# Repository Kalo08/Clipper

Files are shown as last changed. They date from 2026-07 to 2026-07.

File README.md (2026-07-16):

CLIPPER

This project uses a simple robotic arm driven by servos and controlled by a vr headset and controllers. it connects to the headset to feed real time data back to the servos to manipulate the arm. the arm has hair clippers attached, and can be used to cut hair. The headset communicates to a rasberry pi using UDP and sends servo commands. The pi drives the servos through its gpio ports and the servos have power through a simple battery pack and bread board.

https://www.youtube.com/watch?v=h8sehnFcGIc&authuser=0

Heres a YouTube Video explaining how everything works!

clipper



Here are pictures of the finalized arm! It has the a base that allows it to rotate, move up and down, and stay attached ot teh table. That connects to the elbow which allows us to move the clippers even more. 

Wiring: The Pi is powered and connects to the servos. The Pi communicates to our computer. The computer facilitates it comunication with the VR head set. When the VR headset communicates to the Pi, and this tells the pi to activates the servos. The code tells the servos which ones need to go to keep in sync with the VR.

| Item | Qty | Unit Price (USD) | Line Total (USD) | Notes |
| :--- | :--- | :--- | :--- | :--- |
| Raspberry Pi 4 (4GB) | 1 | 55.00 | 55.00 | MSRP; 2GB ~$45 / 8GB ~$75 |
| SG90 Micro Servo | 3 | 4.00 | 12.00 | ~$3-5 each; often cheaper in multipacks |
| Hair Trimmer | 1 | 25.00 | 25.00 | Price provided |
| Aluminum Extrusion (2020 T-slot 1m) | 1 | 12.00 | 12.00 | Varies by profile and length |
| Battery Pack (USB power bank) | 1 | 15.00 | 15.00 | ~10000mAh; Pi 4 needs 5V/3A output |
| Breadboard (830-point) | 1 | 5.00 | 5.00 | Half-size ~$3 |
| Jumper Wires (120pc M-M/M-F/F-F kit) | 1 | 6.00 | 6.00 | Mixed kit |
| Total |  |  | 130.00 |  |

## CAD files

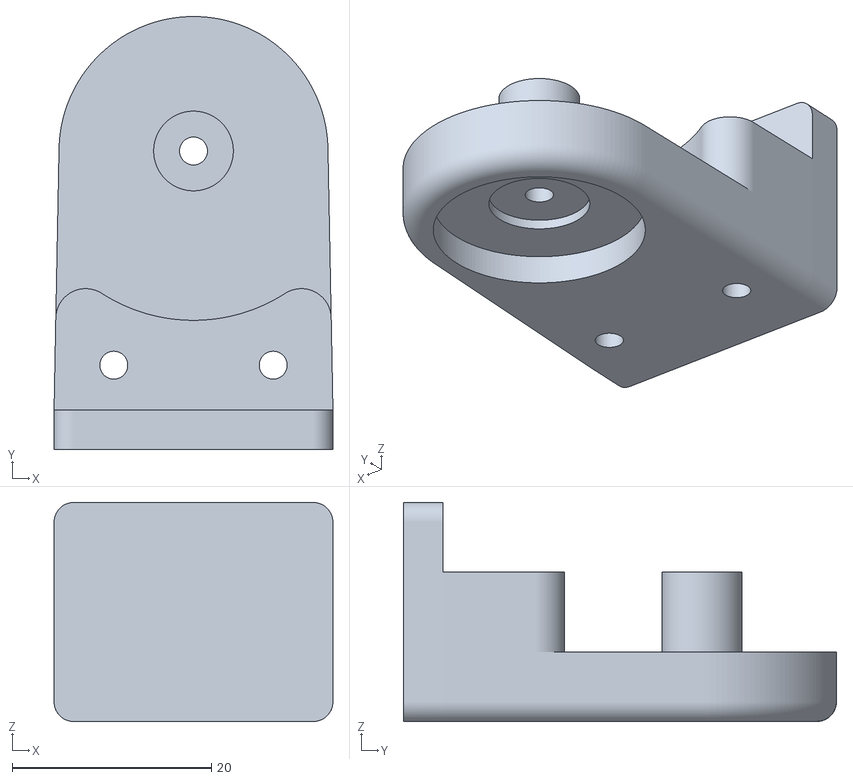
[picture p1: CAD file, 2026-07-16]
CAD /Elbow joint top.stl
28.0 x 43.5 x 22.0

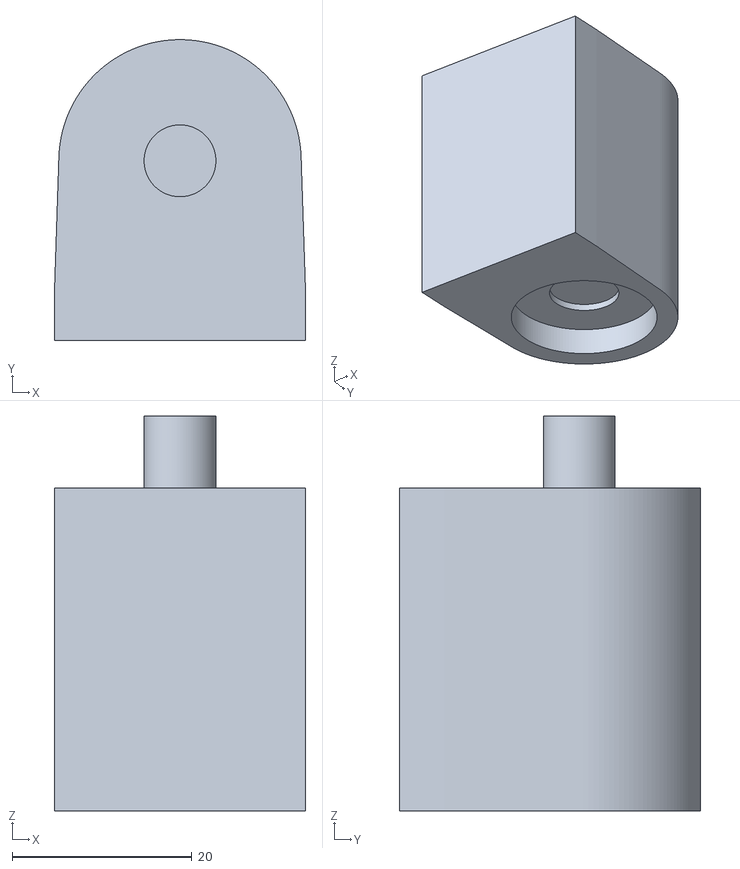
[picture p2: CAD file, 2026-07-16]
CAD /Base joint.stl
28.0 x 33.5 x 44.0

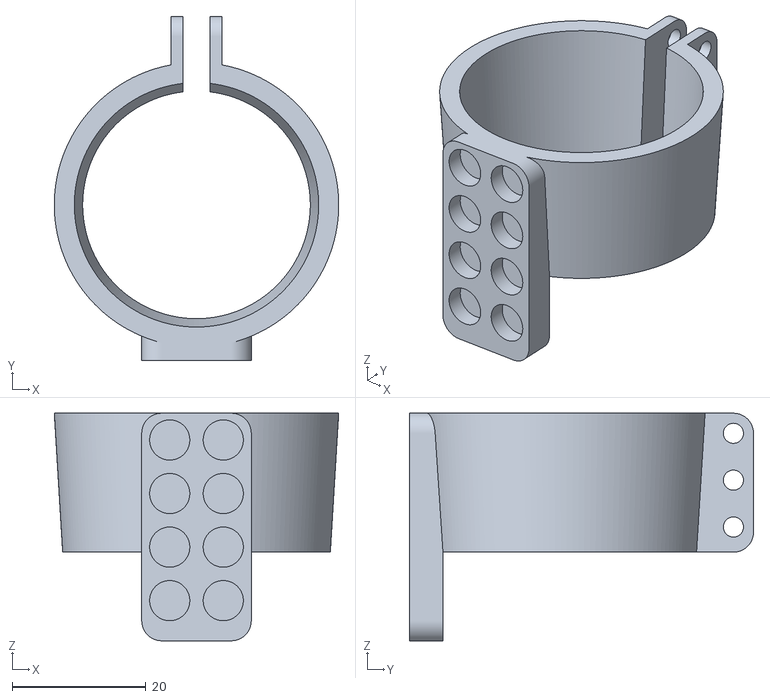
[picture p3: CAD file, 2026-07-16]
CAD /Trimmer holder.stl
42.5 x 51.4 x 34.0

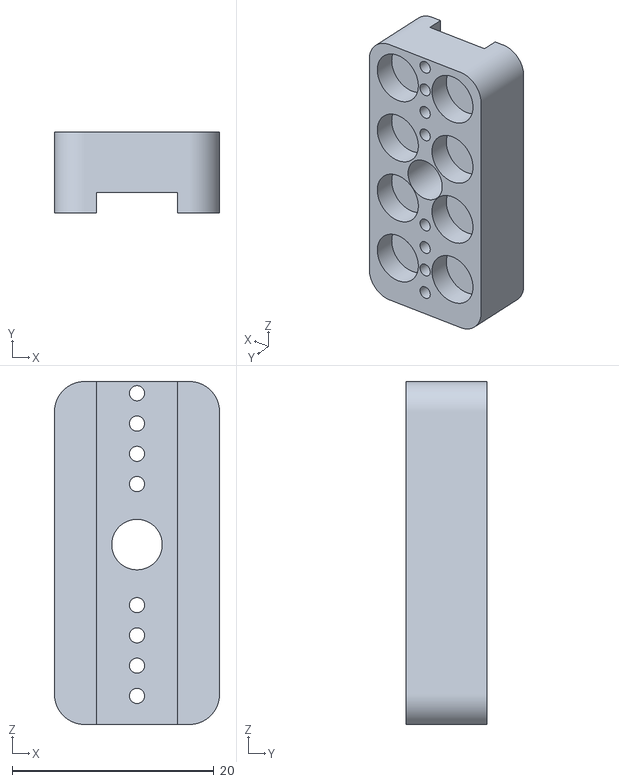
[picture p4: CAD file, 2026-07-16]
CAD /Trimmer holder servo attachment.stl
16.4 x 8.00 x 34.0

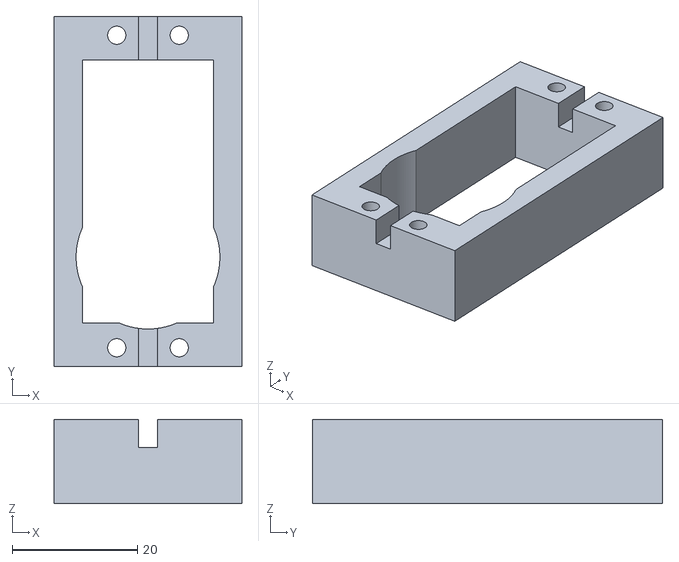
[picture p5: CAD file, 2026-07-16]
CAD /Base servo holder.stl
30.0 x 56.0 x 13.5

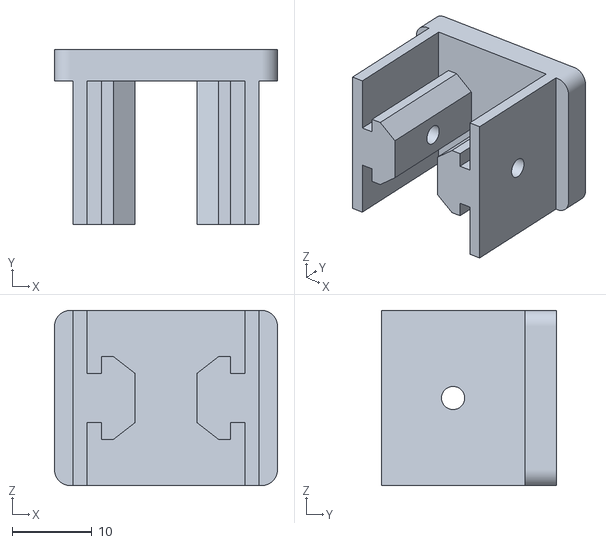
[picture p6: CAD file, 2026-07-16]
CAD /arm attachment.stl
28.0 x 22.0 x 22.0

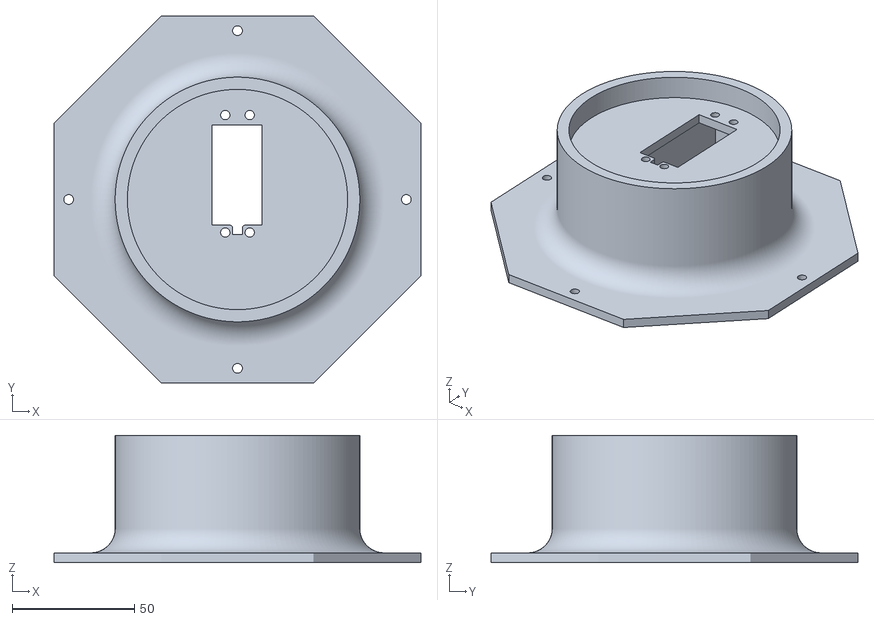
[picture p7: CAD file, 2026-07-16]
CAD /Base bottom.stl
150.0 x 150.0 x 52.0

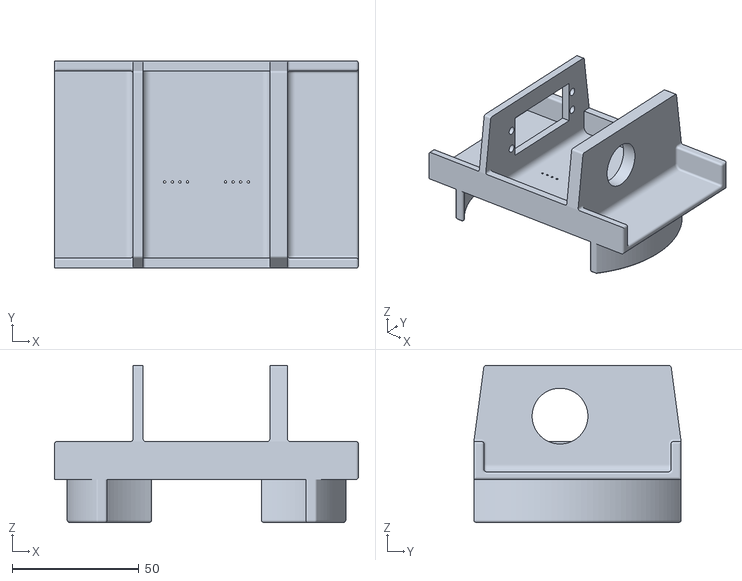
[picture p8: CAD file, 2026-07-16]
CAD /Base top.stl
120.0 x 81.8 x 62.0

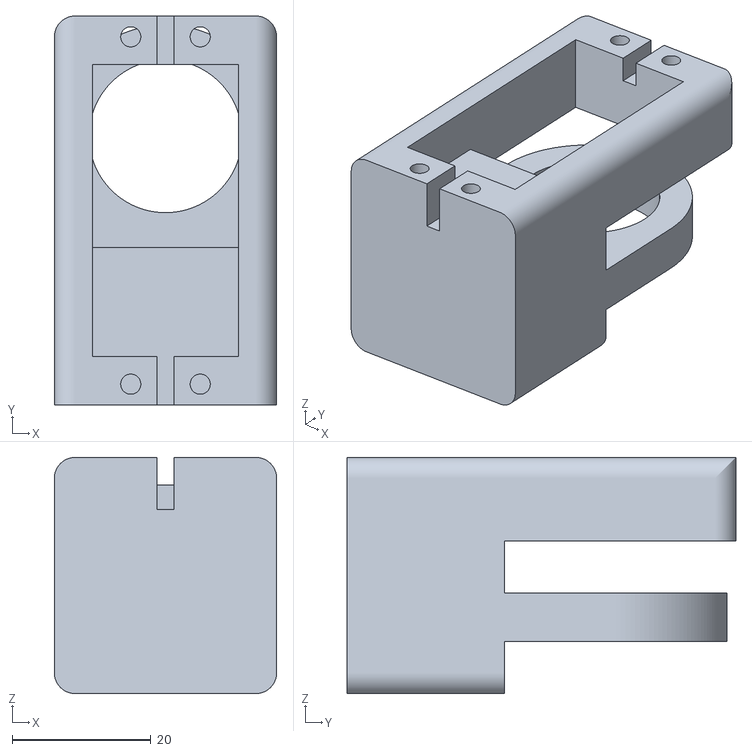
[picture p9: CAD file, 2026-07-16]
CAD /Elbow bottom.stl
32.0 x 56.0 x 34.0

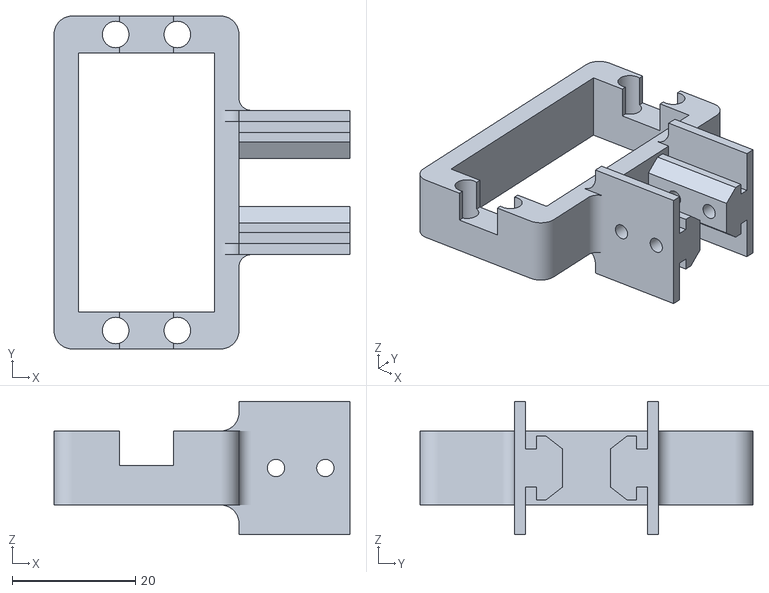
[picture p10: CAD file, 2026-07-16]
CAD /Wrist servo holder.stl
48.0 x 54.0 x 21.6

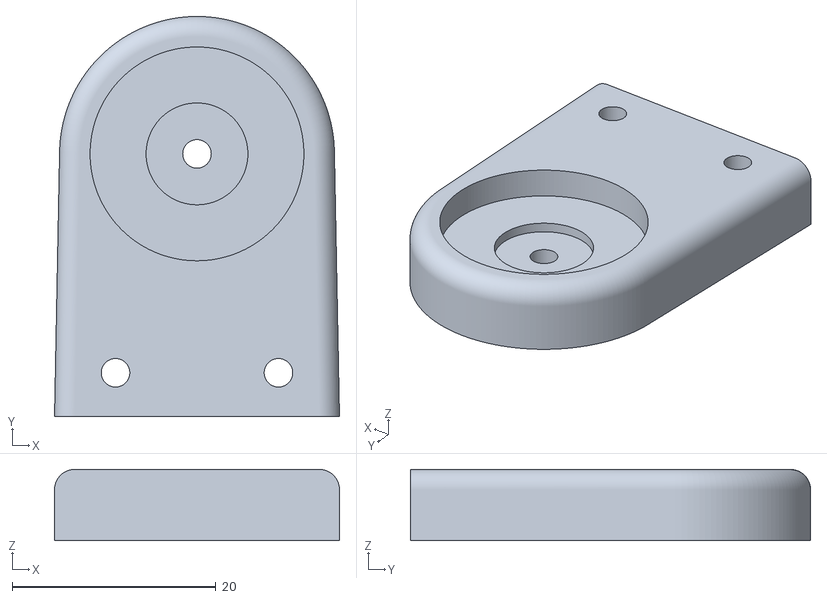
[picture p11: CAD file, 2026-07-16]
CAD /Elbow joint insert.stl
28.0 x 39.3 x 7.00

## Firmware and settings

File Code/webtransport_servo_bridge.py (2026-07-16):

"""
WebTransport (QUIC) → Servo Bridge
Receives compact binary datagrams from the Meta Quest WebXR page
and drives servos directly via Pi GPIO PWM (no PCA9685 driver board).

Packet format (matches webxr_controller.html):
    1 byte  → command byte (0x01 = spin stepper 1 one revolution)
    3 bytes → servo angles [S1, S2, S3], each 0-180
        byte 0 → S1 angle  (0–180)  base rotation (pan / yaw)        → GPIO27 (physical pin 13)
        byte 1 → S2 angle  (0–180)  joint on base (tilt / pitch)     → GPIO17 (physical pin 11)
        byte 2 → S3 angle  (0–180)  roll                             → GPIO22 (physical pin 15)
        byte 3 → S4 angle  (0–180)  driven by analog trigger, 90=up/0=down → GPIO4 (physical pin 7)
        byte 4 → trigger strength (0-255), informational only

Wiring (servo → Pi 4):
    Signal → GPIO27 / GPIO17 / GPIO22 / GPIO4 (physical pins 13 / 11 / 15 / 7)
    S2B (second shoulder servo, mirrored follower of S2) → GPIO18 (physical pin 12)
    V+     → 5–6 V external supply for servos (NOT the Pi's 5V pin)
    GND    → common ground with the Pi

Dependencies (install on the Pi):
    pip install aioquic gpiozero lgpio RPi.GPIO

gpiozero + lgpio drive the servo PWM directly (no daemon needed) via the
modern GPIO chardev interface — works on current Raspberry Pi OS releases
where the unmaintained `pigpio` package is no longer available.

Generate your TLS cert first:
    python setup_cert.py

Run:
    python webtransport_servo_bridge.py

Then open webxr_controller.html on the Meta Quest Browser,
paste the cert hash printed by setup_cert.py, and hit Connect.
"""

import asyncio
import logging
import signal
import sys
import threading
import time
from datetime import datetime
from pathlib import Path

# ── gpiozero / lgpio (direct GPIO PWM for servos) ─────────────────────────────
SIMULATE = False
_AngularServo = None
try:
    from gpiozero import AngularServo, Device
    from gpiozero.pins.lgpio import LGPIOFactory
    Device.pin_factory = LGPIOFactory()
    _AngularServo = AngularServo
except Exception as e:
    SIMULATE = True
    print(f"[bridge] gpiozero/lgpio unavailable ({e}) — SIMULATE mode (no servo output).")

# ── Stepper GPIO import ───────────────────────────────────────────────────────
try:
    import RPi.GPIO as GPIO
    GPIO.setmode(GPIO.BCM)
    GPIO.setwarnings(False)
    _GPIO_OK = True
except (ImportError, RuntimeError):
    _GPIO_OK = False

# ── aioquic imports ───────────────────────────────────────────────────────────
try:
    from aioquic.asyncio import serve
    from aioquic.asyncio.protocol import QuicConnectionProtocol
    from aioquic.h3.connection import H3_ALPN, H3Connection
    from aioquic.h3.events import (
        DatagramReceived,
        H3Event,
        HeadersReceived,
        WebTransportStreamDataReceived,
    )
    from aioquic.quic.configuration import QuicConfiguration
    from aioquic.quic.events import ProtocolNegotiated, QuicEvent
except ImportError:
    print("ERROR: 'aioquic' not installed.  Run:  pip install aioquic")
    sys.exit(1)

# ── Config ────────────────────────────────────────────────────────────────────
HOST      = "0.0.0.0"
PORT      = 4433
CERT_FILE = Path("cert.pem")
KEY_FILE  = Path("key.pem")
WT_PATH   = "/servo"        # Must match the URL in webxr_controller.html

# GPIO pin (BCM numbering) for each servo's PWM signal wire
SERVO_GPIO = {"s1": 27, "s2": 17, "s3": 22, "s4": 4, "s2b": 18}

# s2b is a second shoulder servo mounted on the OPPOSITE side of the joint
# from s2, driving the first linkage in unison with it. Because it faces the
# other way it always follows s2 at the mirrored angle (180 - s2) — driving
# both to the same angle would make them fight each other and stall.
SERVO_FOLLOWERS = {"s2": ("s2b", lambda a: 180 - a)}

# The follower tracks the master's position from this long ago, tracing the
# same motion path uniformly time-shifted. Only useful for a TRUE timing
# mismatch — a lead/lag that flips with direction (in sync one way, delayed
# the other) is an angle offset and needs TRIM below, not delay.
SERVO_FOLLOWER_DELAY_S = 0.0

# Constant trim added to s2b's mirrored angle, correcting a horn seated a few
# degrees off true mirror. Tune this ONLY once behavior is consistent
# (stable power, no random twitching) — calibrating against noise is
# meaningless. Symptom of needing trim: lead/lag that flips with sweep
# direction, the same way every sweep.
SERVO_FOLLOWER_TRIM_DEG = 0.0

# Startup pose per servo (defaults to 0).
# s1 starts centred (90 = "facing forward" once calibrated) rather than at
# its 0 default — with the s1 mirror below, initial_angle=0 would otherwise
# swing the base to its opposite physical extreme for no reason at cold start.
# s2 starts at 90 = arm straight up; s2b mirrors that as 180 - 90 = 90.
SERVO_INIT = {"s1": 90, "s2": 90, "s2b": 90}

# Pulse width range for 0-180 degrees (microseconds) — standard hobby servo range
SERVO_MIN_US = 500
SERVO_MAX_US = 2500

# Hard safety limits — servos are never driven outside these ranges, regardless
# of what a client requests. Physical range is still 0-180 (see AngularServo
# below); this just clamps the usable travel.
#   s1 (base)          — full range, no clamp
#   s2/s3/s4 (joints)  — clamped to ±85° around centre (90°), a few degrees
#                        short of the mechanical stops
SERVO_LIMITS = {
    "s1":  (0, 180),
    "s2":  (5, 90),     # 90 = straight up; angle DECREASES as the arm tips forward
    "s2b": (90, 175),   # mirrored image of s2's range (180 - [5, 90])
    "s3":  (5, 175),
    "s4":  (5, 175),
}

# NOTE: an s2 direction-reversal mirror (angle -> 180 - angle) was tried here
# and reverted — logical angle 0 is confirmed to be the arm's straight-up
# rest pose, and mirroring the whole 0-180 range moves that reference to the
# opposite physical extreme (0 -> 180), which is NOT "up". A full-range
# reversal is only safe when the joint's reference position sits at the
# CENTRE (90) rather than an endpoint — see s1 below, where that holds.
#
# s1 (base) swings the wrong horizontal direction — target-right commands
# spin it left. s1's reference ("facing forward" at calibration) is at the
# CENTRE of its range (90°), not an endpoint, so mirroring is safe here:
# 180 - 90 = 90, the centre — and therefore the calibration reference —
# stays fixed while the direction of swing flips.
SERVO_INVERT = {"s1"}


def _phys_angle(key: str, angle: float) -> float:
    return 180 - angle if key in SERVO_INVERT else angle

# A4988 stepper driver — stepper 1 (BCM numbering)
STEP1_PIN       = 23   # physical pin 16 — A4988 STEP
DIR1_PIN        = 24   # physical pin 18 — A4988 DIR
STEPPER1_STEPS  = 200  # steps per full revolution (1.8°/step motor, full-step mode)
STEPPER1_DELAY  = 0.002  # seconds per half-pulse — lower = faster spin

# ── Logging ───────────────────────────────────────────────────────────────────
logging.basicConfig(
    level=logging.INFO,
    format="%(asctime)s  %(levelname)-7s  %(message)s",
    datefmt="%H:%M:%S",
)
log = logging.getLogger("wt-bridge")
logging.getLogger("aioquic").setLevel(logging.WARNING)   # silence QUIC noise

# ── Servo state ───────────────────────────────────────────────────────────────
# Bookkeeping must start at the SAME logical angle each servo is actually
# initialised to (SERVO_INIT), or the slew loop's first move jump-cuts from
# a stale "0" instead of continuing smoothly from where the servo really is.
current_angles = {key: SERVO_INIT.get(key, 0) for key in SERVO_GPIO}
target_angles  = dict(current_angles)
_slew_stop = None   # threading.Event, created when the slew loop starts

# Stats
pkt_count  = 0
last_stats = time.monotonic()


servos = {}   # key -> AngularServo instance, populated by init_servos()


def init_servos():
    if SIMULATE:
        log.info("SIMULATE mode — gpiozero not initialised.")
        return
    for key, gpio in SERVO_GPIO.items():
        init_angle = SERVO_INIT.get(key, 0)
        servos[key] = _AngularServo(
            gpio,
            initial_angle=_phys_angle(key, init_angle),
            min_angle=0,
            max_angle=180,
            min_pulse_width=SERVO_MIN_US / 1_000_000,
            max_pulse_width=SERVO_MAX_US / 1_000_000,
        )
        log.info(f"  GPIO{gpio} → {key.upper()} initialised ({init_angle}°)")


def move_servo(key: str, angle: int):
    # Master/slave: commands only set TARGETS. The pose loop below owns all
    # hardware writes, pushing the latest commanded pose out each tick —
    # master and follower (s2b) in the same tick, no rate limiting.
    lo, hi = SERVO_LIMITS[key]
    angle = max(lo, min(hi, angle))
    target_angles[key] = angle


def _pose_loop():
    from collections import deque
    # 50 Hz — matches the servo pulse rate. Updating pulse widths faster
    # than the servos consume them (e.g. 100 Hz) risks mid-pulse glitches
    # with software-timed PWM, which shows up as random twitching.
    TICK = 0.02
    # -1: the loop ordering (target read → write → history append) already
    # contributes one tick of inherent lag
    delay_ticks = max(0, round(SERVO_FOLLOWER_DELAY_S / TICK) - 1)
    # Per-master ring buffer of past positions; the oldest entry is the
    # master's angle SERVO_FOLLOWER_DELAY_S ago once the buffer fills.
    history = {m: deque([current_angles[m]] * (delay_ticks + 1),
                        maxlen=delay_ticks + 1)
               for m in SERVO_FOLLOWERS}

    while not _slew_stop.is_set():
        # Followers chase the master's (possibly delayed) position
        for master, (fkey, transform) in SERVO_FOLLOWERS.items():
            flo, fhi = SERVO_LIMITS[fkey]
            target_angles[fkey] = max(flo, min(fhi,
                transform(history[master][0]) + SERVO_FOLLOWER_TRIM_DEG))

        # Write the latest pose straight through — no stepping. The servos
        # hold whatever pose was last written (PWM stays active) until the
        # next change arrives.
        for key in SERVO_GPIO:
            tgt = target_angles[key]
            if current_angles[key] != tgt:
                current_angles[key] = tgt
                if not SIMULATE:
                    servos[key].angle = _phys_angle(key, tgt)

        for master in history:
            history[master].append(current_angles[master])
        time.sleep(TICK)


def start_pose_loop():
    global _slew_stop
    _slew_stop = threading.Event()
    threading.Thread(target=_pose_loop, daemon=True, name="servo-pose").start()
    log.info("Servo pose loop started (50 Hz, direct pose writes).")


def cleanup_servos():
    if not SIMULATE:
        # Stop the pose loop, then release the pins WITHOUT moving anything —
        # servos hold their last commanded position while powered and simply
        # stop receiving pulses where they are.
        if _slew_stop is not None:
            _slew_stop.set()
            time.sleep(0.05)
        for key, servo in servos.items():
            try:
                servo.close()
            except Exception:
                pass
    if _GPIO_OK:
        GPIO.cleanup()


def bar(a: int, w: int = 16) -> str:
    n = int((a / 180) * w)
    return f"[{'#'*n}{'-'*(w-n)}]{a:>4}°"


# ── Per-channel servo "spin" test ────────────────────────────────────────────
SERVO_SPIN_CMDS = {0x02: "s1", 0x03: "s2", 0x04: "s3"}

# Guards against overlapping motions: pressing a spin button twice (or angle
# packets streaming in mid-sweep) would otherwise interleave two writers on
# the same servo, which shows up as erratic continuous sweeping.
_busy_lock = threading.Lock()
_busy: set[str] = set()


def _claim(key: str) -> bool:
    with _busy_lock:
        if key in _busy:
            return False
        _busy.add(key)
        return True


def _release(key: str):
    with _busy_lock:
        _busy.discard(key)


def sweep_servo(key: str, delay: float = 0.01):
    """Blocking sweep lo -> hi -> lo across this servo's SERVO_LIMITS — run off the event loop (see run_in_executor call site)."""
    if SIMULATE:
        log.info(f"SIMULATE: would sweep servo {key}.")
        return
    if not _claim(key):
        log.info(f"Servo {key.upper()} sweep already running — ignored.")
        return
    lo, hi = SERVO_LIMITS[key]
    try:
        for angle in list(range(lo, hi + 1, 2)) + list(range(hi, lo - 1, -2)):
            move_servo(key, angle)
            time.sleep(delay)
        log.info(f"Servo {key.upper()} sweep complete.")
    finally:
        _release(key)


# ── Stepper 1 (A4988) ─────────────────────────────────────────────────────────

def init_stepper1():
    if not _GPIO_OK:
        return
    GPIO.setup(STEP1_PIN, GPIO.OUT)
    GPIO.setup(DIR1_PIN, GPIO.OUT)
    GPIO.output(STEP1_PIN, GPIO.LOW)
    GPIO.output(DIR1_PIN, GPIO.HIGH)
    log.info(f"  GPIO {STEP1_PIN} → STEP1, GPIO {DIR1_PIN} → DIR1 initialised")


def spin_stepper1(steps: int = STEPPER1_STEPS, delay: float = STEPPER1_DELAY):
    """Blocking step loop — run this off the asyncio event loop (see run_in_executor call site)."""
    if not _GPIO_OK:
        log.info(f"SIMULATE: would spin stepper 1 for {steps} steps.")
        return
    if not _claim("stepper1"):
        log.info("Stepper 1 already spinning — ignored.")
        return
    try:
        for _ in range(steps):
            GPIO.output(STEP1_PIN, GPIO.HIGH)
            time.sleep(delay)
            GPIO.output(STEP1_PIN, GPIO.LOW)
            time.sleep(delay)
        log.info(f"Stepper 1 spun {steps} steps.")
    finally:
        _release("stepper1")


_last_seq = None


def handle_packet(data: bytes):
    """
    Decode an incoming datagram.
      1 byte  -> command byte (0x01 = spin stepper 1 one revolution)
      6 bytes -> servo angle packet [seq, s1, s2, s3, s4, strength]

    seq is a wrapping 0-255 counter. QUIC datagrams arrive unordered, so a
    stale mid-motion packet can land AFTER the newest one — without this
    check it would overwrite the final position with an earlier angle.
    Packets more than half the wrap window behind the newest seen are
    discarded as stale.
    """
    global pkt_count, _last_seq

    if len(data) == 1:
        cmd = data[0]
        if cmd == 0x01:
            log.info("Command received: spin stepper 1")
            asyncio.get_event_loop().run_in_executor(None, spin_stepper1)
        elif cmd in SERVO_SPIN_CMDS:
            key = SERVO_SPIN_CMDS[cmd]
            log.info(f"Command received: spin servo {key.upper()}")
            asyncio.get_event_loop().run_in_executor(None, sweep_servo, key)
        return

    if len(data) < 6:
        return

    seq = data[0]
    if _last_seq is not None:
        ahead = (seq - _last_seq) & 0xFF
        if ahead == 0 or ahead > 128:   # duplicate or stale (arrived late)
            return
    _last_seq = seq

    s1, s2, s3, s4 = data[1], data[2], data[3], data[4]

    # Validate range — ignore garbage
    if not (0 <= s1 <= 180 and 0 <= s2 <= 180 and 0 <= s3 <= 180 and 0 <= s4 <= 180):
        return

    # Skip servos mid-sweep so streamed angles don't fight the sweep loop
    for key, val in (("s1", s1), ("s2", s2), ("s3", s3), ("s4", s4)):
        if key not in _busy:
            move_servo(key, val)
    pkt_count += 1

    # Print live status every 30 packets instead of every packet
    # to avoid flooding the terminal while keeping feedback visible
    if pkt_count % 30 == 0:
        ts = datetime.now().strftime("%H:%M:%S")
        print(
            f"\r{ts}  S1{bar(s1)}  S2{bar(s2)}  S3{bar(s3)}  S4{bar(s4)}  "
            f"[{pkt_count} pkts]   ",
            end="", flush=True,
        )


# ── WebTransport protocol ─────────────────────────────────────────────────────

class ServoHandler(QuicConnectionProtocol):
    """
    Minimal WebTransport server handler.
    Accepts any WebTransport session on WT_PATH and processes incoming datagrams.
    """

    def __init__(self, *args, **kwargs):
        super().__init__(*args, **kwargs)
        self._h3: H3Connection | None = None
        self._wt_sessions: set[int] = set()   # active WebTransport session IDs

    def quic_event_received(self, event: QuicEvent):
        if isinstance(event, ProtocolNegotiated):
            self._h3 = H3Connection(self._quic, enable_webtransport=True)

        if self._h3:
            for h3_event in self._h3.handle_event(event):
                self._h3_event(h3_event)

    def _h3_event(self, event: H3Event):
        if isinstance(event, HeadersReceived):
            # Inspect CONNECT request headers for WebTransport handshake
            headers = {k: v for k, v in event.headers}
            method  = headers.get(b":method", b"").decode()
            path    = headers.get(b":path",   b"").decode()

            if method == "CONNECT" and path == WT_PATH:
                # Accept the WebTransport session
                self._h3.send_headers(
                    stream_id=event.stream_id,
                    headers=[(b":status", b"200")],
                )
                self._wt_sessions.add(event.stream_id)
                addr = self._quic._network_paths[0].addr if self._quic._network_paths else "?"
                log.info(f"WebTransport session opened from {addr}  (stream {event.stream_id})")
            else:
                # Reject unknown paths
                self._h3.send_headers(
                    stream_id=event.stream_id,
                    headers=[(b":status", b"404")],
                )

        elif isinstance(event, DatagramReceived):
            # QUIC datagrams arrive here — these are our servo packets
            handle_packet(event.data)

        elif isinstance(event, WebTransportStreamDataReceived):
            # Also accept data on WebTransport streams (fallback from browser)
            handle_packet(event.data)


# ── Main ──────────────────────────────────────────────────────────────────────

async def main():
    if not CERT_FILE.exists() or not KEY_FILE.exists():
        print(f"\nERROR: {CERT_FILE} or {KEY_FILE} not found.")
        print("  Run:  python setup_cert.py\n")
        sys.exit(1)

    config = QuicConfiguration(
        alpn_protocols=H3_ALPN,
        is_client=False,
        max_datagram_frame_size=65536,   # enable QUIC datagrams
    )
    config.load_cert_chain(str(CERT_FILE), str(KEY_FILE))

    init_servos()
    init_stepper1()
    start_pose_loop()

    print(f"\n{'=' * 62}")
    print(f"  WebTransport Servo Bridge  (QUIC / UDP-like datagrams)")
    print(f"  Listening on  https://{HOST}:{PORT}{WT_PATH}")
    print(f"  Simulate mode: {SIMULATE}")
    print(f"\n  Servo GPIO map (BCM numbering):")
    for k, gpio in SERVO_GPIO.items():
        print(f"    {k.upper()} → GPIO{gpio}")
    print(f"\n  Stepper 1 (A4988) GPIO map:")
    print(f"    STEP1 → GPIO {STEP1_PIN} (BCM)")
    print(f"    DIR1  → GPIO {DIR1_PIN} (BCM)")
    print(f"\n  Steps:")
    print(f"    1. Find Pi IP:   hostname -I")
    print(f"    2. Open webxr_controller.html on the Quest Browser")
    print(f"    3. Set Pi IP + cert hash (from setup_cert.py) → Connect")
    print(f"\n  Ctrl+C to stop.")
    print(f"{'=' * 62}\n")

    stop = asyncio.get_event_loop().create_future()

    def _sig(*_):
        if not stop.done():
            stop.set_result(None)

    loop = asyncio.get_event_loop()
    for sig in (signal.SIGINT, signal.SIGTERM):
        try:
            loop.add_signal_handler(sig, _sig)
        except NotImplementedError:
            pass

    server = await serve(
        host=HOST,
        port=PORT,
        configuration=config,
        create_protocol=ServoHandler,
    )
    try:
        await stop
    except (asyncio.CancelledError, KeyboardInterrupt):
        pass
    finally:
        server.close()

    print()
    log.info(f"Shutting down.  Total packets received: {pkt_count}")
    cleanup_servos()


if __name__ == "__main__":
    try:
        asyncio.run(main())
    except KeyboardInterrupt:
        pass

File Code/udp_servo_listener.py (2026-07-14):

"""
UDP Servo Data Listener - Test Script
Receives raw UDP packets from Android APK and decodes servo control data
intended for a Raspberry Pi 3.

Expected packet format (sent from Android APK):
  - Simple CSV:   "S1:90,S2:45,S3:120"
  - JSON:         {"s1": 90, "s2": 45, "s3": 120}
  - Binary:       [servo_id (1 byte), angle (1 byte), ...]
  - Raw bytes:    b'\x01\x5a\x02\x2d'  (servo_id, angle pairs)

Run this on your PC or Raspberry Pi 3 to verify the APK is sending
correctly before wiring up actual servo GPIO control.
"""

import socket
import struct
import json
import time
import argparse
from datetime import datetime

# ──────────────────────────────────────────────
# Configuration
# ──────────────────────────────────────────────
DEFAULT_HOST = "0.0.0.0"   # Listen on all interfaces
DEFAULT_PORT = 5005         # Match this in your Android APK
BUFFER_SIZE  = 1024         # Max bytes per UDP packet


# ──────────────────────────────────────────────
# Packet parsers
# ──────────────────────────────────────────────

def try_parse_json(data: bytes) -> dict | None:
    """Try to decode the payload as JSON."""
    try:
        obj = json.loads(data.decode("utf-8"))
        if isinstance(obj, dict):
            return obj
    except (json.JSONDecodeError, UnicodeDecodeError):
        pass
    return None


def try_parse_csv(data: bytes) -> dict | None:
    """
    Try to decode the payload as CSV servo pairs.
    Accepted formats:
        "S1:90,S2:45"
        "1:90,2:45"
        "90,45,120"   (positional, no servo-id prefix)
    """
    try:
        text = data.decode("utf-8").strip()
        servos = {}

        if ":" in text:
            for part in text.split(","):
                part = part.strip()
                if ":" in part:
                    label, val = part.split(":", 1)
                    label = label.strip().upper().lstrip("S")
                    servos[f"S{label}"] = int(val.strip())
        else:
            for i, val in enumerate(text.split(","), start=1):
                servos[f"S{i}"] = int(val.strip())

        return servos if servos else None
    except (ValueError, UnicodeDecodeError):
        pass
    return None


def try_parse_binary(data: bytes) -> dict | None:
    """
    Try to decode the payload as raw binary servo pairs.
    Format: alternating bytes  [servo_id, angle, servo_id, angle, ...]
    Angle clamped to 0-180.
    """
    if len(data) < 2 or len(data) % 2 != 0:
        return None
    servos = {}
    for i in range(0, len(data), 2):
        servo_id = data[i]
        angle    = data[i + 1]
        if not (0 <= angle <= 180):
            return None   # Doesn't look like servo angles
        servos[f"S{servo_id}"] = angle
    return servos if servos else None


def parse_packet(data: bytes) -> tuple[str, dict | None]:
    """
    Attempt all parsers in order of likelihood.
    Returns (format_name, servo_dict) or (format_name, None) if unknown.
    """
    result = try_parse_json(data)
    if result:
        return "JSON", result

    result = try_parse_csv(data)
    if result:
        return "CSV", result

    result = try_parse_binary(data)
    if result:
        return "BINARY", result

    return "UNKNOWN", None


# ──────────────────────────────────────────────
# Display helpers
# ──────────────────────────────────────────────

def servo_bar(angle: int, width: int = 20) -> str:
    """Render a simple ASCII bar for a servo angle (0-180)."""
    filled = int((angle / 180) * width)
    bar = "#" * filled + "-" * (width - filled)
    return f"[{bar}] {angle:>3}°"


def print_servos(fmt: str, servos: dict, addr: tuple, raw: bytes):
    ts = datetime.now().strftime("%H:%M:%S.%f")[:-3]
    print(f"\n{'─' * 52}")
    print(f"  {ts}  from {addr[0]}:{addr[1]}   [{fmt}]")
    print(f"  raw ({len(raw)} bytes): {raw.hex(' ').upper()}")
    print()
    for name, angle in sorted(servos.items()):
        print(f"  {name:>4}  {servo_bar(angle)}")
    print(f"{'─' * 52}")


def print_unknown(addr: tuple, raw: bytes):
    ts = datetime.now().strftime("%H:%M:%S.%f")[:-3]
    print(f"\n[{ts}] UNRECOGNISED packet from {addr[0]}:{addr[1]}")
    print(f"  raw ({len(raw)} bytes): {raw.hex(' ').upper()}")
    try:
        print(f"  utf-8: {raw.decode('utf-8')!r}")
    except UnicodeDecodeError:
        pass


# ──────────────────────────────────────────────
# Main listener
# ──────────────────────────────────────────────

def listen(host: str, port: int, packet_limit: int | None):
    sock = socket.socket(socket.AF_INET, socket.SOCK_DGRAM)
    sock.setsockopt(socket.SOL_SOCKET, socket.SO_REUSEADDR, 1)
    sock.bind((host, port))
    sock.settimeout(1.0)   # Allow Ctrl-C to work cleanly

    print(f"\n{'=' * 52}")
    print(f"  UDP Servo Listener")
    print(f"  Listening on {host}:{port}")
    print(f"  Waiting for packets from Android APK ...")
    if packet_limit:
        print(f"  Will stop after {packet_limit} packets.")
    print(f"  Press Ctrl+C to quit.")
    print(f"{'=' * 52}\n")

    packet_count = 0
    stats = {"json": 0, "csv": 0, "binary": 0, "unknown": 0}

    try:
        while True:
            try:
                data, addr = sock.recvfrom(BUFFER_SIZE)
            except socket.timeout:
                continue

            packet_count += 1
            fmt, servos = parse_packet(data)

            if servos:
                stats[fmt.lower()] = stats.get(fmt.lower(), 0) + 1
                print_servos(fmt, servos, addr, data)
            else:
                stats["unknown"] += 1
                print_unknown(addr, data)

            if packet_limit and packet_count >= packet_limit:
                print(f"\nReached packet limit ({packet_limit}). Stopping.")
                break

    except KeyboardInterrupt:
        pass
    finally:
        sock.close()
        print(f"\n{'=' * 52}")
        print(f"  Session ended. {packet_count} packet(s) received.")
        print(f"  JSON={stats['json']}  CSV={stats['csv']}  "
              f"BINARY={stats['binary']}  UNKNOWN={stats['unknown']}")
        print(f"{'=' * 52}\n")


# ──────────────────────────────────────────────
# CLI entry point
# ──────────────────────────────────────────────

if __name__ == "__main__":
    parser = argparse.ArgumentParser(
        description="Test listener for UDP servo data from an Android APK."
    )
    parser.add_argument(
        "--host", default=DEFAULT_HOST,
        help=f"Interface to bind (default: {DEFAULT_HOST})"
    )
    parser.add_argument(
        "--port", type=int, default=DEFAULT_PORT,
        help=f"UDP port to listen on (default: {DEFAULT_PORT})"
    )
    parser.add_argument(
        "--limit", type=int, default=None,
        help="Stop after N packets (default: run forever)"
    )
    args = parser.parse_args()
    listen(args.host, args.port, args.limit)

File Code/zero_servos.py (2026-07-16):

"""
Zero servos — drives every servo to the arm's zeroed pose and HOLDS it there
(PWM stays active) until you press Ctrl+C, then releases the pins.

Note: "zeroed pose" is not 0° for every servo — S2B is mounted on the opposite
side of the shoulder joint from S2, so its mirrored zero is 180°.

Run this with the bridge STOPPED (Ctrl+C webtransport_servo_bridge.py first),
otherwise the GPIO pins are already claimed and this script will fail to
open them.

Run:
    source venv/bin/activate
    python zero_servos.py
"""

import time

try:
    from gpiozero import AngularServo, Device
    from gpiozero.pins.lgpio import LGPIOFactory
    Device.pin_factory = LGPIOFactory()
except Exception as e:
    print(f"ERROR: gpiozero/lgpio not available ({e})")
    print("  Run:  pip install gpiozero lgpio")
    raise SystemExit(1)

# Must match SERVO_GPIO in webtransport_servo_bridge.py
# s1 -> pin 13, s2 -> pin 11, s3 -> pin 15, s4 -> pin 7, s2b -> pin 12
SERVO_GPIO = {"s1": 27, "s2": 17, "s3": 22, "s4": 4, "s2b": 18}

# Angle each servo holds in the zeroed pose. S2's straight-up is at 90 on the
# physical arm (forward-only from there); s2b mirrors it (180 - 90 = 90).
# S1 rests centred at 90 ("facing forward"). Keep in sync with SERVO_INIT in
# webtransport_servo_bridge.py.
ZERO_ANGLES = {"s1": 90, "s2": 90, "s3": 0, "s4": 0, "s2b": 90}

SERVO_MIN_US = 500
SERVO_MAX_US = 2500

print("=" * 60)
print("  Zeroing all servos")
print("  Make sure webtransport_servo_bridge.py is NOT running.")
print("=" * 60)

servos = {}
for key, gpio in SERVO_GPIO.items():
    angle = ZERO_ANGLES[key]
    try:
        servo = AngularServo(
            gpio,
            initial_angle=angle,
            min_angle=0,
            max_angle=180,
            min_pulse_width=SERVO_MIN_US / 1_000_000,
            max_pulse_width=SERVO_MAX_US / 1_000_000,
        )
        servos[key] = servo
        print(f"  GPIO{gpio} → {key.upper()} holding at {angle}°")
    except Exception as e:
        print(f"  GPIO{gpio} ({key.upper()}) unavailable: {e}")

print("\nHolding zero pose — press Ctrl+C to release the servos and exit.")
try:
    while True:
        time.sleep(1)
except KeyboardInterrupt:
    pass

for key, servo in servos.items():
    servo.close()

print("\nDone. Servos released.")

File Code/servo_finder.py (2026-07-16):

"""
Servo pin finder — figures out which physical servo is wired to which GPIO.

Pulses one GPIO at a time and asks you to watch which servo wiggles.
Run it with the bridge STOPPED (Ctrl+C webtransport_servo_bridge.py first),
otherwise the pins are already claimed and nothing will move.

Run:
    source venv/bin/activate
    python servo_finder.py
"""

import time

try:
    from gpiozero import AngularServo, Device
    from gpiozero.pins.lgpio import LGPIOFactory
    Device.pin_factory = LGPIOFactory()
except Exception as e:
    print(f"ERROR: gpiozero/lgpio not available ({e})")
    print("  Run:  pip install gpiozero lgpio")
    raise SystemExit(1)

# (BCM GPIO, physical pin) — bridge pins first, then neighbours in case a
# wire landed one pin off from where it was supposed to go.
CANDIDATES = [
    (27, 13),   # bridge S1 — base rotation
    (17, 11),   # bridge S2 — joint on base
    (22, 15),   # bridge S3
    (4,   7),   # bridge S4 — trigger-driven
    (18, 12),   # bridge S2B — second shoulder servo (mirrored follower of S2)
    (10, 19),   # below pin 15's area
    (9,  21),
    (11, 23),
]

print("=" * 60)
print("  Servo pin finder")
print("  Watch the servos — each GPIO gets wiggled one at a time.")
print("  Make sure webtransport_servo_bridge.py is NOT running.")
print("=" * 60)

for gpio, pin in CANDIDATES:
    input(f"\nPress Enter to wiggle GPIO{gpio} (physical pin {pin}) ... ")
    try:
        s = AngularServo(
            gpio,
            initial_angle=90,
            min_angle=0,
            max_angle=180,
            min_pulse_width=0.0005,
            max_pulse_width=0.0025,
        )
    except Exception as e:
        print(f"  GPIO{gpio} unavailable: {e}")
        continue
    for _ in range(3):
        s.angle = 60
        time.sleep(0.4)
        s.angle = 120
        time.sleep(0.4)
    s.angle = 90
    time.sleep(0.3)
    s.close()
    print(f"  Done. If a servo just wiggled, its signal wire is on GPIO{gpio} (pin {pin}).")

print("\nAll candidates tested.")
print("Match what you saw against the bridge map: S1=GPIO27  S2=GPIO17  S3=GPIO22  S4=GPIO4")

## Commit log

2026-07-16 Guard against overlapping servo sweeps and add servo pin finder
    Spin commands ran unguarded in executor threads, so a double button
    press interleaved two sweep loops on one servo (erratic continuous
    sweeping). Streamed angle packets could also fight an active sweep.
    Both paths now respect a per-motor busy set, and servo_finder.py
    wiggles one GPIO at a time to identify which servo is on which pin.
2026-07-16 servo handle
2026-07-16 Added BOM
    [BOM.csv]
2026-07-16 organized into folder
    [Base bottom.stl, Base joint.stl, Base servo holder.stl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]
